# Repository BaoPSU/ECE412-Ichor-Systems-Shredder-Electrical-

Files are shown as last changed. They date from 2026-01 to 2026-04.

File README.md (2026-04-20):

# Universal Plastic Shredder V2.0 — Electrical System

**ECE 412 Senior Project Development I/II · Portland State University · Winter–Spring 2026**

Industry Sponsor: **MME / Ichor Systems** (Bridget Lannigan)
Faculty Advisors: Prof. Andrew Greenberg, Dr. Jonathan Bird (EE), Robert Paxton (ME)

**Team "I'm so Shredded inc.":**

| Name | Email |
|---|---|
| Bao Nguyen | baon@pdx.edu |
| Fearghus Tyler | fearghus@pdx.edu |
| Yaqoub Rabiah | yrabiah@pdx.edu |
| Fox Kang | foxkang@pdx.edu |

---

## Project Overview

Ichor Systems generates significant plastic waste (PVC, polypropylene, LDPE) during semiconductor equipment manufacturing. Existing commercial shredders are either too expensive or underpowered for their thick-material needs (0.25–0.5" rigid sheets). This project designs and builds the **electrical control and power system** for a new industrial-grade plastic shredder — Universal Plastic Shredder V2.0.

The mechanical structure and cutting blades are handled by a separate ME team. The EE team is responsible for:

- VFD-based motor control (3–5 HP, target 70–90 RPM output shaft speed)
- HMI operator interface (ESP32 with display, RS485/MODBUS to VFD)
- Safety systems: two-hand start, emergency stop, lid interlock, overload/overcurrent protection
- PLC ladder logic for control sequencing (DirectLogic 205 / Direct Automation)
- Status indicator lights (Power, Running, Fault)
- Electrical protection: fuses, breakers, motor contactor, thermal shutdown

Design follows **NFPA 70 (NEC)** guidance and **NEMA enclosure** practices. Total project budget is $3,000 (EE portion ~$1,000).

---

## Requirements Summary

**Must:**
- Shred plastic into ~1-inch pieces when integrated with ME system
- Use a controllable VFD; support 3–5 HP motor at 70–90 RPM
- Follow NFPA-70 (NEC) electrical design guidance
- Include emergency stop, overcurrent/overload protection, and at least one safety interlock
- Include an HMI for operator control and status display
- Stay within $3,000 total project budget

**Should:**
- Include clear status and fault indicator lights
- Follow NEMA enclosure guidelines
- Have clearly labeled controls

**May (if time/budget allow):**
- Wireless monitoring (read-only)
- Data logging
- Additional safety sensing (capacitive touch, thermal)

---

## Repository Structure

```
docs/           Project proposal, team contract, HMI options matrix
BOM/            Bill of materials and component selection spreadsheets
CAD/            Mechanical CAD zip archive and Inventor part files (Part1–Part10)
electrical/     Circuit logic diagrams and deadman circuit documentation
PLC/            Shredder ladder logic program
HMI/            HMI project file (MagicPanel .mgp)
```

---

## System Architecture

**Hardware subsystems:**
- AC power input → disconnect → fuses/breakers
- VFD (motor speed and direction control via MODBUS/RS485)
- 3–5 HP motor + gearbox (ME interface)
- ESP32 HMI display (operator interface)
- Safety circuit: two-hand start buttons, E-stop, lid interlock, motor contactor

**PLC (DirectLogic 205 rack — Direct Automation):**
- Ladder logic controls motor run/stop sequencing and safety interlocks
- Program file: `PLC/Shredder_Ladder_logic_v1.dmd`

**Software (Arduino/C++ on ESP32):**
- HMI: displays Ready / Running / Fault state, motor speed, fault messages
- Safety input handling: continuously monitors E-stop, interlocks, two-hand start
- Control logic: manages system states (Idle → Ready → Running → Fault)
- VFD interface: sends run/stop/speed commands, reads fault signals via MODBUS

**Operator workflow:**
1. Power on → safety check
2. Press two-hand start buttons simultaneously to run motor
3. Hand-feed plastic sheets into shredder
4. Normal stop via Stop button, or E-stop if needed
5. Collect shredded output (~1-inch pieces)

---

## Prior Work

A 2023–2024 PSU capstone team built a working 2 HP plastic shredder for the EPL that shredded household plastics with basic VFD, two-hand start, and E-stop. This project scales to industrial-grade plastics and adds motor current monitoring, automatic jam-clearing (auto forward/reverse), thermal shutdown, improved safety interlocks, a proper contactor, and a full HMI.

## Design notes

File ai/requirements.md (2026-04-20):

# Requirements

## Must (M)
| ID | Requirement |
|---|---|
| M1 | Electrical system must safely support shredding plastic into ~1" pieces when integrated with ME system |
| M2 | Controllable VFD must be used |
| M3 | Electrical design must follow NFPA-70 (NEC) guidance |
| M4 | Emergency stop must safely shut down the system |
| M5 | Overcurrent and overload protection must be included |
| M6 | At least one safety interlock must be used |
| M7 | Motor speed must operate around 70–90 RPM |
| M8 | VFD must support a 3–5 HP motor |
| M9 | System must include an HMI for operator control and status display |
| M10 | Total project cost (EE + ME) must remain under $3,000 |

## Should (S)
| ID | Requirement |
|---|---|
| S1 | System should include clear status and fault indicators |
| S2 | Electrical enclosure should follow NEMA-guided practices |
| S3 | Controls should be clearly labeled and easy to understand |

## May (O)
| ID | Requirement |
|---|---|
| O1 | EE electrical cost may target ~$1,000 (subject to change) |
| O2 | Wireless monitoring may be explored (read-only) |
| O3 | Data logging may be implemented |
| O4 | Additional safety sensing (capacitive touch, thermal) may be explored |

## Performance Specs
| Parameter | Value |
|---|---|
| Target shred size | ~1 inch |
| Motor shaft speed | 70–90 RPM (adjustable via VFD) |
| Plastic materials | High-density PVC, PP, LDPE |
| Plastic thickness | 0.25–0.5 inch |
| Plastic width | 4–12 inch |
| Power input | 120 VAC or 208–240 VAC facility supply |
| Total budget | $3,000 (EE + ME) |

## Pass/Fail Test Criteria
- Shreds plastic into ~1" pieces
- VFD controls motor speed with safe start/stop
- E-stop immediately shuts down the system
- Safety interlocks prevent operation when access points are open
- Overcurrent/overload protection triggers under unsafe electrical conditions
- System operates at ~80–90 RPM without electrical faults or exposed wiring

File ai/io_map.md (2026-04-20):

# PLC I/O Map — DirectLOGIC 205 D2-09B-1

## Rack Slot Layout
| Slot | Module | Type | Points |
|---|---|---|---|
| 1 | H2-DM1E | CPU / Ethernet | — |
| 2 | D2-08ND3 | 8-ch DI (24VDC) | X0–X7 |
| 3 | F2-06AD-1 | 6-ch AI (4–20mA / 0–10V) | — |
| 4 | F2-04RTD | 4-ch RTD input | — |
| 5 | D2-08TD2 | 8-ch DO (12–24VDC sourcing) | Y0–Y7 |
| 6 | F2-02DAS-2 | 2-ch AO (4–20mA / 0–10V) | — |
| 7–9 | D2-Fill | Reserved | — |

## Discrete Outputs (D2-08TD2, Slot 5)
| Address | Load | Notes |
|---|---|---|
| Y0 | Mitsubishi SD-N35 Contactor coil A1 | +24VDC via DF103V 1/2A fuse |

## Analog Output (F2-02DAS-2, Slot 6)
| Channel | Destination | Signal |
|---|---|---|
| CH1 | VFD HY02D211B-T terminal AL | 0–10V speed command via ZipLink ZL-RTB20 |

## Output Module — AC Relay (D2-08TA, separate)
| Address | Load | Notes |
|---|---|---|
| OUT0 | TX Contactor (GH15-BN) coil A1 | Via ZipLink, 120VAC common fused 1A slow blow |
| OUT1 | BUS Contactor (GH15-BN) coil A1 | Via ZipLink |
| OUT2 | F1 Contactor (GH15-BN) coil A1 | Via ZipLink |
| OUT3 | Thermal Overload RTD32-180 NC (95→96) | Feeds F2 contactor coil |

## Power Distribution Summary
| Source | Destination | Protection |
|---|---|---|
| Wall AC Line | EURO S10H-5H fuse block | 25A (PSU branch), 1A (PLC branch) |
| NDR-480-24 +V | Pushbutton commons (Fwd, Rev, DM1, DM2) | 1.5A fast blow via EURO S4LH |
| NDR-480-24 –V | Contactor A2, D2-08TD2 COM, D2-08ND3 COM, D2-04RTD COM | Direct return |
| Wall AC (via power switch) | PLC L terminal | 1A fast blow |
| Wall AC (via power switch) | PSU L terminal | 25A slow blow |

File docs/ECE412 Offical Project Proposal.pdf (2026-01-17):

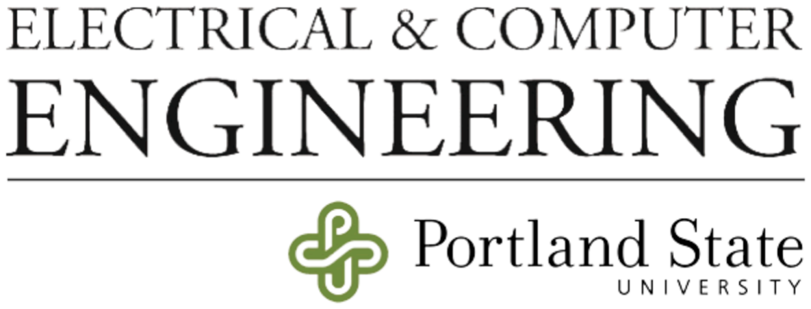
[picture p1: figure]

# Capstone Project Proposal:

# Universal Plastic Shredder V2.0

—————————————————————————————————————— ECE 412 - Senior Project Development I Winter 2026

——————————————————————————————————————— Prof. Andrew Greenberg
Industry Sponsor: MME / Ichor Systems
Faculty Advisor(s): Dr. Jonathan Bird (EE), Robert Paxton (ME)
Authors: Bao Nguyen, Fearghus Tyler, Yaqoub Rabiah, Fox Kang Team Name: I’m so Shredded inc.
Contact: yrabiah@pdx.edu

## Executive Summary

This project is sponsored by MME / Ichor Systems, a company that develops equipment for the semiconductor industry. The main users of this project are workers who handle plastic waste at the company.

The problem is that the company produces a large amount of plastic waste and does not have a cost-effective way to shred and reuse it. Buying large industrial shredders is very costly, and smaller shredders are not strong or safe enough for the types of plastic being handled. The plastic waste includes materials such as PVC, polypropylene (PP), and LDPE, often in the form of thick or rigid parts rather than thin packaging.

This capstone project focuses only on the electrical control and power system for a plastic shredder designed to handle these materials. The mechanical structure, cutting blades, and physical frame are designed by a separate Mechanical Engineering team and are not part of this proposal.

The Electrical Engineering team will design and build the systems that power and control the shredder. This includes motor control, VFD selection, electrical protection, safety interlocks, emergency stop circuits, and operator controls. These systems must be sized and rated based on the expected plastic types and thicknesses (approximately 0.25–0.5 inches thick) so the motor, VFD, and electrical components can be properly selected and tested.

This project will have an impact on the company because it helps reduce waste and allows plastic to be reused instead of being thrown away, which saves money and benefits the environment.

The capstone will be completed over two academic terms at Portland State University, beginning in Winter 2026 and concluding in Spring 2026. During this time, the Electrical Engineering team will design, build, and test the electrical control and safety systems while coordinating with the Mechanical Engineering team for system integration.

By the end of Spring 2026, we will deliver a functional electrical control system integrated with the shredder, along with design documentation and testing results, to the industry sponsor.

## 1. Background and Research

### 1.1 Sponsor Overview

- Ichor Systems is a company that designs and manufactures equipment used in semiconductor production. They focus on systems that safely deliver gas and chemicals needed to make computer chips. These systems control how much gas or liquid is used during the process like etching, cleaning, and coating.
- Ichor also makes metal and plastic ports for the machine. There machines weld, machine, and treat surfaces. And so that is why they produce so much plastic waste when developing these products.
- Ichor Systems headquarters are located in Fremont, California and have facilities across the United States and in other countries. They support over 2,000 employees and major semiconductor manufacturers around the world.

### 1.2 Technology Domain and Context

- Technical Domain:
- This project focuses on electrical control and safety systems used to operate industrial recycling equipment. The scope includes motor control, electrical protection, safety circuits, and operator interfaces. Mechanical structure and cutting mechanisms are handled by a separate Mechanical Engineering team.
- Why These Systems Exist:
- Plastic shredders are used to reduce plastic waste into smaller pieces so it can be recycled or reused. Electrical control systems are required to safely power and control the motors used in shredding equipment and to protect both the operator and the machine.
- How similar Systems Work:
- Most industrial shredders use electric motors controlled by a Variable Frequency Drive (VFD). Safety systems such as emergency stops, interlocks, and overload protection are used to shut the system down if unsafe conditions occur.
- Project Context:
- This shredder will be used as part of Ichor Systems’ waste-handling process to support recycling and reduce plastic waste. This proposal covers only the electrical system required to safely operate the shredder.

### 1.3 Existing System or Prior Work

- What already exists
- In 2024 a previous Portland State University (PSU) capstone team built a working plastic shredder for the Electronic Prototyping Lab (EPL). This shredder shreds common plastics like detergent bottles and left over 3d prints to smaller pieces. It’s powered by a 2HP electric motor, a gear box torque multiplier, and a Variable Frequency Drive (VFD) to control motor speed. This machine also includes basic safety features such as emergency stop and two-hand operation so the machines cannot run unless both buttons are pressed.
- What we are changing and improving
- Electrical safety and control upgrades
- Motor current monitoring for overload detection
- Automatic forward/reverse to clear jams
■ via current overload detection
- Thermal shutdown for overheating protection
- Lid safety interlock
- Status indicator lights
■ Power on status
■ Running
■ Fault
■ Separated from the VFD
- Improve motor start up and shutdown behavior using VFD settings
- Introduce a speed control knob
- Collect data and tune the operating speed
■ Upgrade for fix speed operation
- Add a motor contactor between VFD and motor for extra protection
- Modify the VFD soft start and stop for safe reverse operation
■ Less stress on the motor
- Optional exploration of additional safety sensing (capacitive touch or thermal sensing) to detect human presence near the feed area and trigger a safe shutdown
- Block diagram or figures of the current system

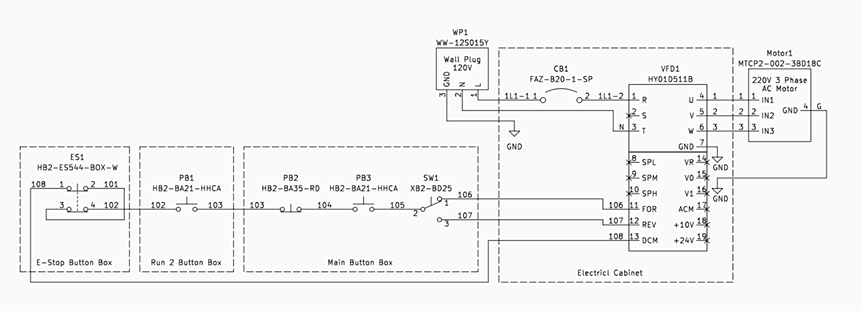
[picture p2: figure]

Electrical Schematic Drawn by: Jasmine Koski (2024)

- The current system takes wall power and sends it to a motor through a VFD. The motor turns a gearbox, which drives the shredder blades. Plastic is fed into the top, shredded inside the cutting chamber, and exits as small pieces. The operator controls the machine using buttons and safety switches.

### 1.5 Research Summary

Commercial Off-the-Shelf Products

### 1. SSI Shredding Systems

a. Model: SSI Dual-Shear® M50
b. What it does: Industrial plastic shredder designed for high-capacity shredding of rigid plastics, containers, and packaging. Uses dual-shaft shear cutters.
c. Suitability:Very effective but expensive and large. It is designed for full-scale recycling facilities, which may be more capacity than needed for an in-house prototype. So expensive that they won't inquire about you unless you are working for the big companies.

### 2. Vecoplab Vaz Series

a. Model: Vecoplan VAZ 1300
b. What it does: Industrial shredder for plastic waste and other materials. Heavy-duty construction with selectable rotor designs.
c. Suitability: Suitable for heavy industrial use, but also $145,700 and over-powered for our use. Offers good examples of safety features and structural design.

### 3. UNTHA Plastic Shredders

a. Model: UNTHA RS40-4
b. What it does: Medium to heavy industrial plastic shredder with four-shaft cutting. Designed for tough plastics and mixed waste streams.
c. Suitability: Professional machine with strong construction. A good industrial standard shredder, but buying one is likely outside the sponsor’s budget considering they don't even list the price.

Open Source Projects

- Project name and license
- Plastic Shredder 2.0
- What it provides
- Open-source designs and documentation for plastic shredders, mainly the electrical control side of things
- What parts are useful
- Example VFD control wiring
- PLC ladder logic structure
- Safety interlock and emergency stop ideas
- Sensor input handling
- General control panel layout ideas

- Limitations or risks
- Most open-source control projects are not designed for industrial environments and do not meet important safety and electrical standards such as NFPA 70 (National Electrical Code), OSHA safety requirements, UL certification, and NEMA enclosure standards. They often do not include proper grounding, fault protection, emergency stop design, or industrial-grade wiring practices. Because of this, these designs cannot be used directly. They are only useful for learning concepts, while the final system must be redesigned to meet real industrial safety and electrical standards.

Patents, Papers, and Articles

- Citation
- Plastic Recycling Shredder Capstone Report, Portland State University (2023–2024)
- Key ideas or results
- The past team successfully designed and built a functional plastic shredder prototype that could shred household plastic into reusable pieces.
- They tested different cutting tooth geometries and showed how tooth shape affects shredding torque and efficiency.
- The machine included a working VFD, forward/reverse control, two-hand safety start, and emergency stop.
- Relevance to our design
- Their work gives us a proven baseline instead of starting from zero.
- The previous report specifically states the system still needs more safety systems and electrical upgrades before it is fully operational, including better protection hardware, braking, interlocks, and improved control design.
- Our project focuses on scaling to a larger industrial system, so we will redesign the electrical system to meet standards such as NFPA 70, NEMA enclosure requirements, UL-style safety thinking, PLC control, industrial-grade wiring, and improved safety interlocks.

## 2. Product Design Specification(Contract)

### 2.1 Product Overview

- What the product or service does
- The Universal Plastic Shredder V2.0 will be a larger, safer, and more powerful plastic shredding system designed to process tougher industrial plastics such as high-density PVC. It will shred plastic sheets into roughly 1-inch pieces using a geared motor system controlled by a VFD and industrial electrical controls.
- The system will include proper fuses, relays, breakers, safety interlocks, and an emergency stop.
- Who uses it
- The shredder will be used by Ichor Systems technicians and operators who handle plastic waste from manufacturing. It may also be used by PSU faculty and students for demonstration and educational purposes.
- How it is used
- Operators will hand-feed plastic sheets into the shredder. Motor speed (target 70–90 RPM) will be controlled using a VFD-based interface. The electrical system will follow industrial wiring practices and provide clear operator controls and safety protections.
- Why the sponsor wants it
- Ichor produces thick plastic waste that the previous student shredder could not safely handle. They want an industrial-style system that is reliable, safe, and compliant with electrical standards, while staying within the $3000 total project budget. Approximately $1000 is allocated to the Electrical Engineering team, subject to change depending on project needs, funding availability, and component sourcing, and not all allocated funds may be used.

### 2.2 Concept of Operations (ConOps)

- Typical user workflow
- Operator powers on the system
- Performs a safety check
- Starts the motor using the control panel
- Feeds plastic into the shredder
- Stops the system normally or uses the emergency stop if needed
- Collects shredded plastic after shutdown
- Inputs, outputs, and interactions
- Inputs: Plastic material, operator control button presses, VFD control signals, safety sensor signals, and power input.
- Outputs: Shredded plastic pieces (target ~1 inch), system status lights, fault indicators, motor speed control, and safety shutdown responses.

- User Interaction: The operator mainly interacts with the control panel, emergency stop, and feed system. The system provides feedback using indicator lights and controls.
- Possible Future Enhancements (Not Guaranteed):
■ If time and budget allow, the team may explore additional features such as a wireless control interface, touchscreen display, data logging, alternative or non-traditional safety sensors, or improved automation. These features are not required for the core system and will only be considered after a safe, fully working shredder system is complete.
- Lifecycle and deployment context
- The system will be designed and tested at PSU and intended for use in a lab or industrial environment. The goal is a durable and serviceable electrical system that can be safely used beyond the capstone project.

### 2.3 Stakeholders

| Stakeholder | Role | Impact on design
Sponsor: | MME / Ichor Systems | Provides project goals, budget, expectations, and final approval. Supplies requirements and feedback. | Drives performance expectations, safety standards, and budget limits. Requires an industrial-style, safe, and reliable shredder design.
End Users: | Technicians/Operator s at Ichor or PSU EPL | Will use the shredder to process plastic waste. Responsible for daily operation, handling materials, and basic maintenance. | Design must prioritize safety, ease of use, clear controls, proper emergency stops, and durable construction suitable for real operation.
Project Team: | Mechanical + Electrical Students | Designs, builds, and tests the system. The mechanical team handles structure and shredding mechanics. The electrical team handles controls, safety, and power systems. | Decisions on components, control systems, safety features, and wiring standards affect cost, complexity, timeline, and overall functionality.

### 2.4 Requirements

Must Requirements

- M1: The electrical system must safely support shredding plastic into ~1-inch pieces when integrated with the mechanical system
- M2: A controllable VFD must be used
- M3: Electrical design must follow NFPA-70 (NEC) guidance
- M4: An emergency stop must safely shut down the system
- M5: Overcurrent and overload protection must be included
- M6: At least one safety interlock must be used
- M7: Motor speed must operate around 70–90 RPM
- M8: The VFD must support a 3–5 HP motor
- M9: The system must include an HMI for operator control and status display
- M10: The total project cost (Electrical + Mechanical) must remain under $3000

Should Requirements

- S1: The system should include clear status and fault indicators
- S2: The electrical enclosure should follow NEMA-guided practices
- S3: Controls should be clearly labeled and easy to understand

May Requirements

- O1: The electrical system cost may target approximately $1000, subject to change based on project needs and funding
- O2: Wireless monitoring may be explored
- O3: Data logging may be implemented
- O4: Additional safety sensing may be explored

### 2.5 Specifications (Optional)

- Quantitative performance targets
- Target shred size: ~1 inch pieces
- Target motor speed: 70–90 RPM (adjustable via VFD)
- Plastic material: High-density PVC, polypropylene (PP), and LDPE, 0.25–0.5 inch thick, 4–12 inch width
- Expected duty cycle: abuse it within reason
- Power requirement: Standard facility AC power (120 VAC or higher industrial supply, such as 208–240 VAC, depending on availability)
- Budget limit: $3000 total project budget (EE + ME), electrical portion subject to change
- Sponsor-imposed technical constraints
- Must safely handle tougher plastics than the previous capstone design

- Must follow industrial-style electrical safety (NFPA-70, NEMA enclosure guidance)
- Must include emergency stop and overload protection
- Must be hand-fed in this version (automation optional for future)
- Must be scalable and designed with potential future improvements in mind

### 2.6 Initial Product Design

Hardware Architecture

- Major subsystems
- Power input, disconnect, and electrical protection
- Control and safety systems
■ 2-hand start, E-stop, interlock, other sensors ■ VFD motor controller
■ HMI operator display interface
■ Motor and mechanical drive interface
- L0 Block diagrams

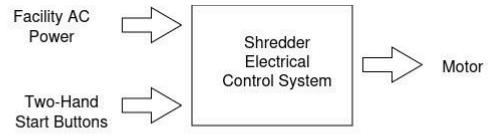
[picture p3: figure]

- L1 Block diagram

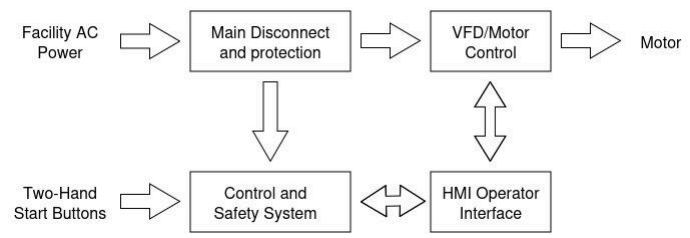
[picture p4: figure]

Software Architecture

- Languages and Environments
- Programming Language: C/C++ (Arduino-style)
- Development Environment: Arduino IDE

- Target Hardware: ESP32 with integrated display (HMI), RS485 to connect to VFD MODBUS safely.
- The Arduino IDE uses a simplified form of C/C++. The code is written in Arduino “sketches,” which are compiled as C/C++ programs.
- Major Modules and Responsibilities
HMI / User Interface
- Displays system status, faults, and speed
- Reads operator inputs (Start, Stop, Reset, Speed control)

Safety Input Handling
- Reads safety signals (emergency stop, two-hand start buttons, interlocks)
- Prevents operation if any safety condition is not met

Control Logic
- Manages system states (Idle, Ready, Running, Fault)
- Controls when the motor is allowed to run

VFD Interface
- Sends run/stop and speed commands to the VFD
- Reads fault or status signals from the VFD if available

Fault Handling
- Detects and displays faults
- Forces safe shutdown behavior

Optional Features
- Basic data logging
- USB serial output for debugging

Data Flow

- Key data paths
- Operator Inputs to ESP32 Control Logic
■ Start, stop, reset, speed settings, and two-hand start buttons are read by the ESP32 through digital inputs or the HMI interface.
- Safety Inputs to Control and Safety Logic
■ Emergency stop, lid/door interlocks, and optional safety sensors are continuously monitored. If any safety condition is violated, the control logic blocks operation or triggers a shutdown.
- ESP32 to VFD
■ The ESP32 sends run/stop commands, direction commands, and speed setpoints to the VFD. The protocol between VFD and ESP32 is unknown, but most commonly used is MODBUS protocol.
- VFD to ESP32
■ The VFD provides status and fault signals back to the ESP32 so the system can display faults and respond safely. Most VFDs from Automation Direct have this capability.

- ESP32 to HMI Display
■ System state, speed, and fault messages are sent to the HMI for operator feedback.
- Storage and communication
- The ESP32 may save simple information such as fault messages or total run time in its built-in memory if needed.
- Communication Interfaces:
■ Digital inputs and outputs for buttons, safety interlocks, and control signals
■ USB connection for programming and debugging
■ Optional Wi-Fi or Bluetooth for monitoring, if used
- No Network Required:
■ The system can operate safely without being connected to the internet or any external network.

User Interface and Experience

- How users interact with the system

The user interacts with the shredder through a simple HMI screen and physical controls. The HMI displays system status such as Ready, Running, or Fault, along with motor speed and basic fault messages.

To start the machine, the operator must press two physical start buttons at the same time. This two-hand control helps keep the operator’s hands away from the feed area during startup. A separate Stop button and Emergency Stop are available to safely shut down the system at any time.

The HMI allows the operator to:
- Start and stop the system
- Adjust motor speed
- View system status and fault messages
- Reset the system after a fault, when safe
- User stories
- As an operator, I want to clearly see whether the system is ready, running, or in a fault state so I know when it is safe to use.
- As an operator, I want the machine to require a two-hand start so my hands are not near moving parts when the shredder begins running.
- As an operator, I want to stop the machine quickly using a stop button or emergency stop if something goes wrong.
- As an operator, I want to see clear fault messages so I know why the system stopped and when it is safe to reset.
- As a technician, I want basic status and fault information on the HMI so troubleshooting is easier.

- As an engineer,I want a maintenance or test page on the HMI that shows the status of safety inputs (such as emergency stop, interlocks, or optional capacitive or thermal sensors) so I can verify that safety systems are working correctly during testing.

Other Considerations

- Security
- The system is designed to operate locally and does not require an internet connection. This reduces security risks related to remote access. Any optional wireless features, if used, will be limited to monitoring and will not allow direct control of the machine. Access to maintenance or test features on the HMI can be restricted to prevent unintended use.
- Safety
- Safety is a primary focus of this project. The electrical system includes an emergency stop, safety interlocks, two-hand start operation, and overload protection to reduce the risk of injury or equipment damage. The control logic is designed so that the system enters a safe state if a fault or unsafe condition is detected. Optional safety sensors, such as capacitive or thermal sensing, may be explored as additional layers of protection but will not replace required safety systems.
- Regulatory compliance
- The electrical system will be designed using industrial-style practices guided by NFPA 70 (National Electrical Code) and general NEMA enclosure guidelines. While full certification (such as UL listing) is outside the scope of this capstone project, safety concepts and wiring practices will follow recognized standards to support safe operation in a lab or industrial environment.

### 2.7 Verification Plan

- How requirements will be tested
- We will test the shredder by running it under real operating conditions. This includes powering the system, controlling it through the VFD and control panel, and shredding real plastic samples that match the sponsor’s material (high-density PVC, 0.25–0.5 in thick). Safety systems such as the emergency stop, interlocks, and overload protection will be tested individually to confirm they work correctly. Torque testing and motor behavior will be verified during initial mechanical testing to ensure the selected motor and gearbox are appropriate.
- Pass/fail criteria
- The shredder must successfully shred plastic into approximately 1-inch pieces.
- The VFD must control motor speed and allow safe start/stop operation.
- The emergency stop must immediately and safely shut down the system.
- Safety interlocks must prevent the system from running when access points are open.

- Overcurrent / overload protection must trigger when unsafe electrical conditions occur.
- System must operate at the target speed (~80–90 RPM)
- The system must operate safely without electrical faults, dangerous exposed wiring, or unsafe behavior.

If any of these fail, the system will be revised and retested.

- Tools and test setups
- Torque testing tools (torque wrench or torque reader as discussed)- could be changed anytime
- VFD configuration and monitoring tools
- Multimeter and electrical testing tools
- Indicator lights / fault monitoring
- Test plastic material supplied by sponsor
- Lab safety supervision during testing

### 2.8 Risks

- Technical risks
- The selected motor or gearbox may not provide enough torque to shred thick PVC material.
- The electrical system may require more protection or safety components than expected.
- Integration between mechanical and electrical systems may be more complex than planned.
- Safety systems (interlocks, E-stop, overload protection) may need redesign to fully meet standards.
- Schedule risks
- Torque testing and motor selection may take longer than expected.
- Mechanical CAD work may delay electrical enclosure planning.
- delivery for motors, VFDs, or electrical components may slow progress.
- Coordination between Mechanical and Electrical teams may impact timing.
- Access to the power lab is unknown
- Resource risks
- Budget limits may restrict component choices.
■ Can also affect the amount of back up equipment
- Availability of used parts or lab equipment may change.
- Limited access to lab space, tools, or testing resources may slow work.
- Mitigation strategies and backup plans
- Perform torque testing early to guide motor and gearbox selection.
- Keep close communication between EE and ME teams to coordinate interfaces.
- Prioritize MUST functionality and safety before optional features.
- Source components early, look for surplus or used equipment to stay inside budget.

- Build in schedule buffer time to handle delays.
- If torque capacity is too low, adjust gearbox ratio or scale mechanical design.

### 2.9 Deliverables

- Project proposal
- Formal written proposal defining scope, objectives, and requirements.(What we are doing here)
- Weekly progress reports
- Short updates documenting progress, challenges, and next steps, scrum.
- Final report
- A full engineering document covering design decisions, analysis, testing, and results.
- Capstone poster
- Would be nice, not necessary
- Brief overview of the main design log documents covering design decisions.
- Working prototype
- Functional electrical control and safety system integrated with the mechanical shredder. Ideally designed in schedule in reference of the ME team.
- Design files and documentation
- Electrical schematics, wiring diagrams, PLC logic (if used), VFD configuration, parts list, safety analysis, and any required NFPA/NEMA compliance documentation to support future use.
- Operators manual
- Debug manual

Delivery Method:

- Github
- Google Drive

## 3. Project Management Plan

### 3.1 Timeline and Milestones

- Research complete by week 3-5
- Initial design finished by week 6-8
- First prototype finished by week 10+
- Integrated prototype 10+
- Final validation 10+

### 3.2 Budget and Resources

The budget is $3,000 for both the ME and EE group.

Item | Cost | Source | When Needed
Motor 3-5 HP? | ~$100-$400? | Second hand? Ask around? Ebay | 3-4th week of the term
VFD? | ~$100-$300? | Reputable online vendor. Automation Direct. Ebay | 3-4th week of the term
Wire/Contacts/Other? | ~$100-$200? | EPL, Ebay, Amazon | 3-4th week of the term

### 3.3 Intellectual Property

- IP ownership
- All work produced during this capstone project will be released as open-source. The project team and Portland State University retain authorship of the work, and the sponsor is permitted to use the results.
- Licensing terms
- Project materials such as source code, schematics, and documentation will be shared under an open-source license to allow reuse, modification, and educational use.
- Sponsor agreements
- The project will follow Portland State University policies and agreements with MME / Ichor Systems. No confidential or proprietary information will be included in the open-source materials.

### 3.4 Team

Team members: Bao Nguyen, Fearghus Tyler, Yaqoub Rabiah, Fox Kang

- Bao Nguyen will focus on documentation and assist with programming and setting up the HMI, including the GUI layout, icons, and status indicators, and assist with connecting the HMI/ESP32 to the VFD.
- Fearghus Tyler will serve as the team lead and primary point of contact with the sponsor, and will focus on research, the bill of materials (BOM), and overall electrical safety planning.
- Yaqoub Rabiah will focus on start/stop controls, emergency stop integration, and VFD selection, wiring, and programming, and may also assist with ESP32 HMI programming as needed.
- Fox Kang will focus on system integration, safety circuit layout, and evaluation of advanced safety sensing such as capacitive touch or thermal sensors.

Roles and responsibilities are subject to change over the course of the project based on project needs and team availability.

### 3.5 Development Tools and Process

- We have a good deal of tested devices to draw from, the shredding industry is fairly old and established.
- For collaboration, a google drive is sufficient.
- Microsoft Planner or Trello used for scheduling.
- Github

### Sponsor Approval

By signing below, the undersigned acknowledges review of this proposal and agrees with the project scope and objectives as described.

Industry Sponsor Representative:

Name:_Bridget Lannigan__________

Organization:__Ichor Systems_______

Signature:___________________________

Date:___January 16th, 2026_____

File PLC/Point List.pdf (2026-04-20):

# Index

### POINT ASSIGNMENT INDEX

| PAGE NO. | NO. OF SHEETS | DESCRIPTION
| 1.0 | 1.0 | Mitsubishi SD-N35
| 2.0 | 2.0 | Mean Well NDR-480-24
| 3.0 | 3.0 | Direct Logic 205 D2-09B-1
| REV | DATE | DESCRIPTION | Created By | Checked by
| 1.0
| 2.0
| 2.0
| 2.0
| 3.0
| 4.0

# Mitsubishi SD-N35

Mitsubishi SD-N35 | | POINT TYPE
| | Hardware Point | | | | | Virtual Point
Point Description | Origin Address | DO | DI | AO | AI | Pwr | | Destination Address | Destination Description | Notes
Contactor (Mitsubishi SD-N35) ? Coi A1 | 0.0 | 0.0 | 0.0 | 0.0 | 1.0 | 0.0 | Y0 | D2-08TD2 Output Module (12?24VDC)A1 ? DF103V (1/2A slow blow fuse) ?
Contactor (Mitsubishi SD-N35) ? Coi A2 | | 0.0 | 0.0 | 0.0 | 0.0 | 1.0 | 0.0 | -V | NDR-480-24 Power Supply | A2 ? direct return to power supply
Contactor (Mitsubishi SD-N35) ? Lin | L1 | 0.0 | 0.0 | 0.0 | 0.0 | 1.0 | 0.0 | L | Phoenix Contact TMC 83C 15A (290761 L1 ? Phoenix Contact fuse breaker ?
Contactor (Mitsubishi SD-N35) ? LoaT1 | | 0.0 | 0.0 | 0.0 | 0.0 | 1.0 | 0.0 | R | HY Series VFD (HY02D211B-T) | T1 ? passes through contactor ? sup
| Total Points | =SUM(C5:C8) | =SUM(D5:D8) =SUM(E5:E8) | | =SUM(F5:F8) | =SUM(G5:G8) =SUM(H5:H8)

# Mean Well NDR-480-24

Mean Well NDR-480-24 | | POINT TYPE
| | Hardware Point | | | | | Virtual Point
Point Description | Origin Address | DO | DI | AO | AI | Pwr | | Destination Address | Destination Description | Notes
DC Power Supply (Mean Well NDR-480- | L | 0.0 | 0.0 | 0.0 | 0.0 | 1.0 | | L | MORSETTITALIA EURO S10H-5H Fuse BloLine from wall -> passes through po
DC Power Supply (Mean Well NDR-480- | N | 0.0 | 0.0 | 0.0 | 0.0 | 1.0 | | N | Neutral Bus | Neutral from supply -> directly con
DC Power Supply (Mean Well NDR-480- | G | 0.0 | 0.0 | 0.0 | 0.0 | 1.0 | | G | Ground Bus | Protective earth -> connected to PS
DC Power Supply (Mean Well NDR-480- | -V | 0.0 | 0.0 | 0.0 | 0.0 | 1.0 | | A2 | Mitsubishi SD-N35 Contactor | -V from power supply -> connected t
DC Power Supply (Mean Well NDR-480- | -V | 0.0 | 0.0 | 0.0 | 0.0 | 1.0 | | COM | D2-08TD2 Output Module | -V from power supply -> connected t
DC Power Supply (Mean Well NDR-480- | -V | 0.0 | 0.0 | 0.0 | 0.0 | 1.0 | | COM | D2-08ND3 Input Module | -V from power supply -> connected t
DC Power Supply (Mean Well NDR-480- | -V | 0.0 | 0.0 | 0.0 | 0.0 | 1.0 | | COM | D2-04RTD Module | -V from power supply -> connected t
DC Power Supply (Mean Well NDR-480- | +V | 0.0 | 0.0 | 0.0 | 0.0 | 1.0 | | IN | MORSETTITALIA EURO S4LH Terminal Bl+24V from power supply -> enters te
| Total Points | 0.0 | 0.0 | 0.0 | 0.0 | 5.0

# Direct Logic 205 D2-09B-1

Direct Logic 205 D2-09B-1 | | POINT TYPE
| | Hardware Point | | | | | Virtual Point
Point Description | Origin Address | DO | DI | AO | AI | Pwr | | Destination Address | Destination Description | Notes
PLC Rack (DirectLOGIC 205) ? Base | Base | 0.0 | 0.0 | 0.0 | 0.0 | 1.0 | ? | D2-09B-1 | Base / Power Unit | Rack base unit providing backplane
PLC Rack (DirectLOGIC 205) ? Line I | L | 0.0 | 0.0 | 0.0 | 0.0 | 1.0 | ? | L | MORSETTITALIA EURO S10H-5H Fuse BloLine from wall -> passes through po
PLC Rack (DirectLOGIC 205) ? Neutra | N | 0.0 | 0.0 | 0.0 | 0.0 | 1.0 | ? | N | Neutral Bus | Neutral from wall -> directly conne
PLC Rack (DirectLOGIC 205) ? Ground | G | 0.0 | 0.0 | 0.0 | 0.0 | 1.0 | ? | G | Ground Bus | Protective earth -> connected to PL
PLC Rack (DirectLOGIC 205) ? Slot 1 | Slot 1 | 0.0 | 0.0 | 0.0 | 0.0 | 0.0 | ? | H2-DM1E | CPU / Ethernet Module | CPU module with built-in Ethernet p
PLC Rack (DirectLOGIC 205) ? Slot 2 | Slot 2 | 0.0 | 8.0 | 0.0 | 0.0 | 0.0 | ? | D2-08ND3 | 8-Point Discrete Input Module | 8-channel 24VDC discrete (digital)
PLC Rack (DirectLOGIC 205) ? Slot 3 | Slot 3 | 0.0 | 0.0 | 0.0 | 6.0 | 0.0 | ? | F2-06AD-1 | 6-Channel Analog Input Module | 6-channel analog input module. Acce
PLC Rack (DirectLOGIC 205) ? Slot 4 | Slot 4 | 0.0 | 0.0 | 0.0 | 4.0 | 0.0 | ? | F2-04RTD | 4-Channel RTD Input Module | 4-channel RTD (Resistance Temperatu
PLC Rack (DirectLOGIC 205) ? Slot 5 | Slot 5 | 8.0 | 0.0 | 0.0 | 0.0 | 0.0 | ? | D2-08TD2 | 8-Point Discrete Output Module | 8-channel 12?24VDC transistor (sour
PLC Rack (DirectLOGIC 205) ? Slot 6 | Slot 6 | 0.0 | 0.0 | 2.0 | 0.0 | 0.0 | ? | F2-02DA-1 | 2-Channel Analog Output Module | 2-channel analog output module. Pro
PLC Rack (DirectLOGIC 205) ? Slot 7 | Slot 7 | ? | ? | ? | ? | ? | ? | D2-Fill | Fill Panel | Blank fill panel. No I/O. Slot rese
PLC Rack (DirectLOGIC 205) ? Slot 8 | Slot 8 | ? | ? | ? | ? | ? | ? | D2-Fill | Fill Panel | Blank fill panel. No I/O. Slot rese
PLC Rack (DirectLOGIC 205) ? Slot 9 | Slot 9 | ? | ? | ? | ? | ? | ? | D2-Fill | Fill Panel | Blank fill panel. No I/O. Slot rese

# DirectLOGIC CPU (H2-DM1E)

DirectLOGIC PLC CPU(H2-DM1E) | | POINT TYPE
| | Hardware Point | | | | | Virtual Point
Point Description | Origin Address | DO | DI | AO | AI | Pwr | | Destination Address | Destination Description | Notes
Power and communication interface | Backplane Connector (Left Edge) | 0.0 | 0.0 | 0.0 | 0.0 | 1.0 | 0.0 | D2-09B-1 Base Slot 1 Connector | Provides power and backplane commun ?
Ground reference | Backplane GND | 0.0 | 0.0 | 0.0 | 0.0 | 1.0 | 0.0 | D2-09B-1 Base Ground Bus | Common ground for logic power | ?
| Total Points | =SUM(C5:C6) | =SUM(D5:D6) | =SUM(E5:E6) | =SUM(F5:F6) | =SUM(G5:G6) =SUM(H5:H6)

# Output Module (D2-08TA)

Output Module (D2-08TA) | | POINT TYPE
| | Hardware Point | | | | | Virtual Point
Point Description | Origin Address | DO | DI | AO | AI | Pwr | | Destination Address | Destination Description | Notes
Output Common (Hot) | C | 1.0 | 0.0 | 0.0 | 0.0 | 1.0 | 0.0 | 120 V Hot Bus | ZipLink Terminal Block (ZL-RTB20-OU120 V hot feed shared by all output
Output 0 | OUT0 | 1.0 | 0.0 | 0.0 | 0.0 | 0.0 | 0.0 | A1 | TX Contactor (GH15-BN) | Drives TX coil via ZipLink
Output 1 | OUT1 | 1.0 | 0.0 | 0.0 | 0.0 | 0.0 | 0.0 | A1 | BUS Contactor (GH15-BN) | Drives BUS coil via ZipLink
Output 2 | OUT2 | 1.0 | 0.0 | 0.0 | 0.0 | 0.0 | 0.0 | A1 | F1 Contactor (GH15-BN) | Drives F1 coil via ZipLink
Output 3 | OUT3 | 1.0 | 0.0 | 0.0 | 0.0 | 0.0 | 0.0 | 95.0 | Thermal Overload Relay (RTD32-180)Feeds NC contact 95 ? 96 ? F2 coil
Module Power Feed | Backplane | 0.0 | 0.0 | 0.0 | 0.0 | 1.0 | 0.0 | Slot 3 Connector | PLC base backplane (120 VAC) | No external wiring
| Total Points | =SUM(C5:C10) | =SUM(D5:D10) | =SUM(E5:E10) | =SUM(F5:F10) | =SUM(G5:G10) =SUM(H5:H10)

# HMI (EA9-T6CL-R)

6? C-More color touch panel HMI (EA | | POINT TYPE
| | Hardware Point | | | | | Virtual Point
Point Description | Origin Address | DO | DI | AO | AI | Pwr | | Destination Address | Destination Description | Notes
HMI Serial Comm Port | COM Port | 0.0 | 0.0 | 0.0 | 0.0 | 0.0 | 1.0 | Serial Port | H2-DM1E | Serial link between PLC CPU and C-M
HMI Power +V | +VDC | 0.0 | 0.0 | 0.0 | 0.0 | 1.0 | 0.0 | +V | Rhino power supply(PSB12-030-P) | HMI DC input powered from PSB12-030
HMI Power 0 V | 0VDC | 0.0 | 0.0 | 0.0 | 0.0 | 1.0 | 0.0 | 0V | Rhino power supply(PSB12-030-P) | 0 VDC return to Rhino power supply;
HMI Ground | Ground | 0.0 | 0.0 | 0.0 | 0.0 | 1.0 | 0.0 | Ground | Ground
| Total Points | =SUM(C5:C8) | =SUM(D5:D8) =SUM(E5:E8) | | =SUM(F5:F8) | =SUM(G5:G8) =SUM(H5:H8)

# Output Module (F2-02DAS-2)

Output Module (F2-02DAS-2) | | POINT TYPE
| | Hardware Point | | | | | Virtual Point
Point Description | Origin Address | DO | DI | AO | AI | Pwr | | Destination Address | Destination Description | Notes
Analog Common (CH1) | CH1-V | 0.0 | 0.0 | 1.0 | 0.0 | 0.0 | 0.0 | CM | VFD (GS1-20P2) through Ziplink ZL-R0V1 and CH1-V are internally shorte
Analog Output CH1 | CH1+V | 0.0 | 0.0 | 1.0 | 0.0 | 0.0 | 0.0 | AL | VFD (GS1-20P2) though Ziplink ZL-RT0?10 V speed command to VFD
Module Logic +24 V | +V1 | 0.0 | 0.0 | 0.0 | 0.0 | 1.0 | 0.0 | VDC +24V | PLC Base (D2-09B-1) through ZipLinkPowers analog output circuitry, als
Module Logic 0 V | 0V1 | 0.0 | 0.0 | 0.0 | 0.0 | 1.0 | 0.0 | VDC ? 0V | PLC Base (D2-09B-1) through ZipLinkCommon return for module logic
Slot Power Feed | Backplane | 0.0 | 0.0 | 0.0 | 0.0 | 1.0 | 0.0 | PLC Base Backplane | Internal slot power | No external wiring
| Total Points | =SUM(C5:C9) | =SUM(D5:D9) | =SUM(E5:E9) | =SUM(F5:F9) | =SUM(G5:G9) =SUM(H5:H9)

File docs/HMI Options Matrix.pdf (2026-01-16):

HMI Display Matrix Options
Criteria | Display 1 | Display 2 | Display 3 | Display 4 | Display 5 | Display 6 | Display 7 | Display 8
Manufacturer | AutomationDirect | AutomationDirect | ELECROW | Waveshare | Waveshare | NEXTION | Siemens | Siemens
Model | EA3-T6CL | EA9-T7CL | CrowPanel ESP32-S3 (7") | ESP32-S3-Touch-LCD-7 | ESP32-S3-Touch-LCD-7B (Type B) | NX8048P070-011C (Intelligent Series) | SIMATIC HMI KTP600 (6AV6647-0AC11-3AX0) | SIMATIC HMI SMART 700 IE (6AV6648-0CC11-3AX0)
Screen Size (inches) | 6 | 7 | 7 | 7 | 7 | 7 | 6 | 7
Resolution | 320 × 240 | 800 × 480 | 800 × 480 | 800 × 480 | 1024 × 600 | 800 × 480 | 640 × 480 | 800 × 480
Touch Type | Resistive | Resistive | Capacitive | 5-point capacitive | 5-point capacitive (optional) | Capacitive | Resistive | Resistive
Display Panel | TFT | TFT | TFT (TN) | IPS (170°) | IPS (170°) | TFT LCD (65K color) | TFT LCD | TFT LCD
Mount Type | Panel mount (NEMA 4/4X front) | Panel mount (NEMA 4/4X front) | Standalone acrylic case | Dev board / enclosure DIY | Dev board / enclosure DIY | Panel-mount style (front mount); some versions include enclosure | Panel mount (industrial front mount) | Panel mount (industrial front mount)
MCU | Proprietary | Proprietary | ESP32-S3 (LX6, up to 240 MHz) | ESP32-S3 (LX7 dual-core, up to 240 MHz) | ESP32-S3 (LX7 dual-core, up to 240 MHz) | NXP-based, 200 MHz (on-display MCU) | Proprietary Siemens HMI CPU | Proprietary Siemens HMI CPU
Memory | Internal flash | Internal flash + SD | 4 MB Flash + 8 MB PSRAM | 16 MB Flash + 8 MB PSRAM | 16 MB Flash + 8 MB PSRAM | 128 MB Flash, 512 KB SRAM | Internal (Siemens-managed) | Internal Siemens-managed flash / RAM
IO / Interfaces | None (HMI only) | None (HMI only) | GPIO, UART, I²C, USB, battery | CAN, RS485, UART, I²C, USB-C, TF, sensor headers | CAN, RS485, UART, I²C, USB-C, TF, sensor headers + 5V out | UART (TTL serial) to ESP32/Arduino; onboard features vary by series (often includes GPIO/RTC on Intelligent) | PROFINET, USB (service) | PROFINET (Ethernet), USB (service/programming)
Connectivity | Serial / USB (Ethernet optional) | Serial / USB / Ethernet | Wi-Fi + Bluetooth | Wi-Fi + Bluetooth 5 | Wi-Fi + Bluetooth 5 | None (wired UART; no Wi-Fi on the display itself) | Industrial Ethernet (PROFINET) | Industrial Ethernet (PROFINET)
Development Environment | C-more Micro | C-more EA9 | Arduino, ESP-IDF, PlatformIO, MicroPython, LVGL | Arduino, ESP-IDF, LVGL | Arduino, ESP-IDF, LVGL | Nextion Editor (drag-and-drop HMI + event code on screen) | Siemens TIA Portal / WinCC | WinCC flexible SMART (free)
Operating Voltage | 24 VDC | 24 VDC | 5 VDC | 5 VDC or Li-ion | 5 VDC or Li-ion | 5 V | 24 VDC | 24 VDC
Extra features | — | SD logging (EA9) | Case + speaker/battery interfaces vary | — | Backlight adjustment + battery voltage monitoring + charge indicators | Audio/video/animation support, RTC support (per Intelligent series listing) | Alarms, trends, PLC tag binding | Alarms, trends, PLC tag binding, recipes
Cost | ≈ $470 | ≈ $700–750 | ≈ $50 | ≈ $37–40 | ≈ $34–39 | ≈$122 | ≈ $500–900(Used) | ≈ $130–220 (used market)
Support Level | Medium | Medium | Medium–Low | Medium–High | Medium–High | High | High | High
Support Rationale | Good vendor support, weak onboarding/docs | Same as EA3. I have experince with this. | Mixed docs, more self-debugging | Strong wiki/examples/pinouts | Same as Display 4, plus it’s the “upgraded” higher-res version. Looks like a good balance | Easiest path for buttons + live telemetry via simple serial commands according to reddit. But closed source | Excellent industrial documentation and support, closed ecosystem. Wicked expesnive | Strong Siemens documentation and long-term industrial support; closed ecosystem
Industry Standard? | Yes | Yes | No | No | No | Yes | Yes | Yes

The problem with using an industry-standard HMI is that it often needs extra external modules to work with sensors, buttons, and the motor controller. These extra parts increase the total cost. In comparison, an ESP32-based HMI from Elecrow already includes built-in inputs and communication features, which reduces the number of extra components needed and helps keep the system cheaper and simpler. For example, using the AutomationDirect EA9, the HMI along with the required PLC, digital I/O, and analog I/O modules can cost $700–$1,200+ used, not including the VFD or motor, which are already allocated for this project. In contrast, an open-source ESP32-based HMI such as an Elecrow or Waveshare display, including any required modules to communicate over Modbus, would cost under $150–$300 total but at the cost of not being industry rated.

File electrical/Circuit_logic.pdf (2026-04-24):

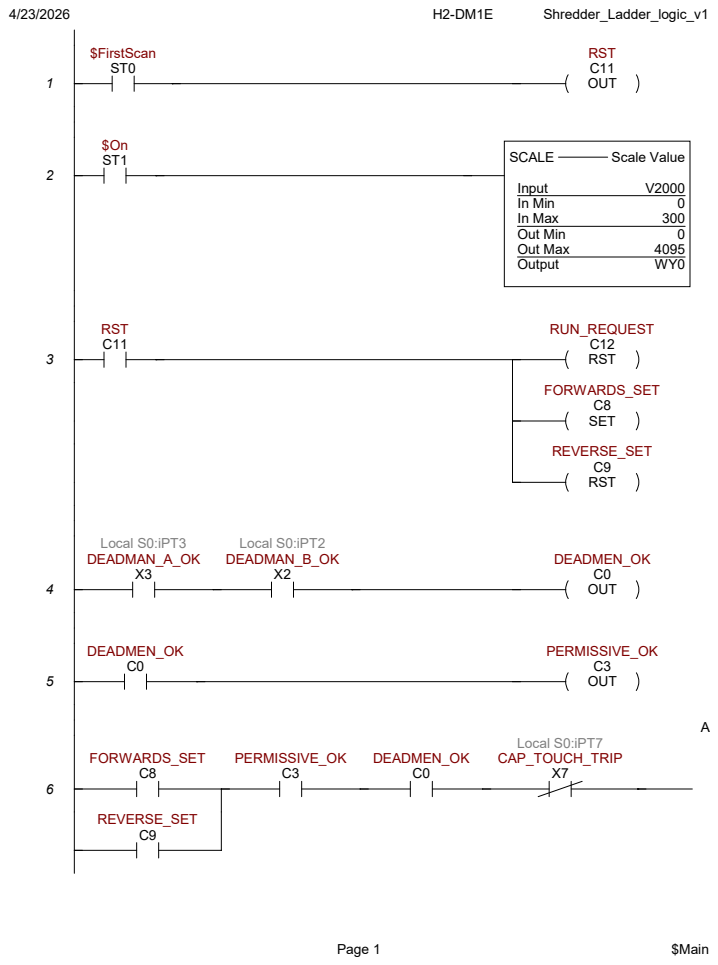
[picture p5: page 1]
Shredder_Ladder_logic_v1; $FirstScan ST0; OUT; RST C11; SCALE; Scale Value; Input; In Min; In Max; Out Min; Out Max; Output; RST; RUN_REQUEST C12; SET; FORWARDS_SET C8; REVERSE_SET C9; Local S0:iPT3 DEADMAN_A_OK X3; Local S0:iPT2 DEADMAN_B_OK X2; DEADMEN_OK C0; PERMISSIVE_OK C3; Local S0:iPT7 CAP_TOUCH_TRIP X7; Page 1; $Main

SET

RUN_REQUEST
C12

A

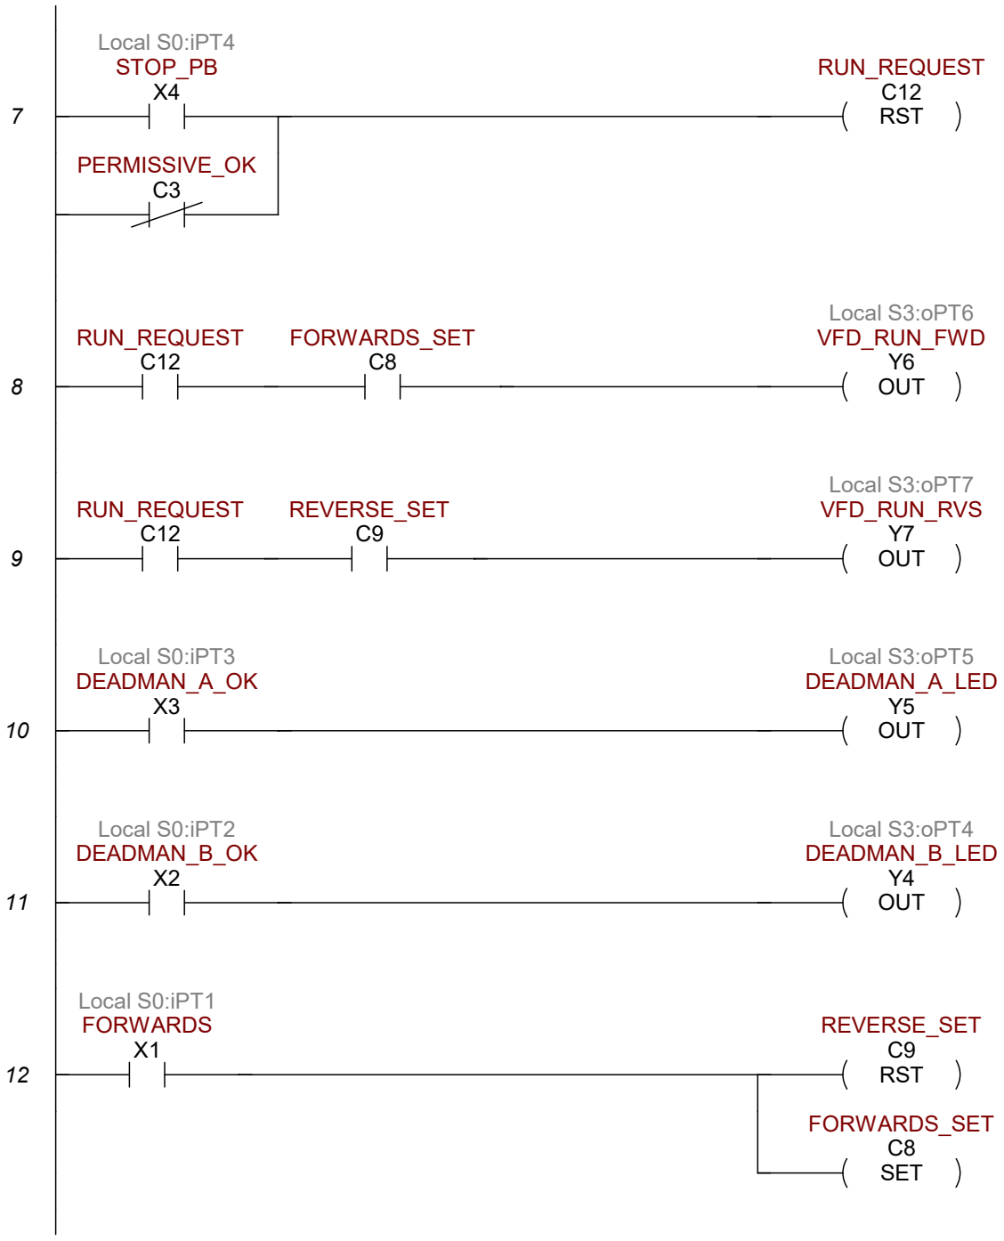
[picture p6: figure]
Local S0:iPT4 STOP_PB X4; RST; RUN_REQUEST C12; PERMISSIVE_OK C3; FORWARDS_SET C8; OUT; Local S3:oPT6 VFD_RUN_FWD Y6; REVERSE_SET C9; Local S3:oPT7 VFD_RUN_RVS Y7; Local S0:iPT3 DEADMAN_A_OK X3; Local S3:oPT5 DEADMAN_A_LED Y5; Local S0:iPT2 DEADMAN_B_OK X2; Local S3:oPT4 DEADMAN_B_LED Y4; Local S0:iPT1 FORWARDS X1; SET

Page 2 | $Main

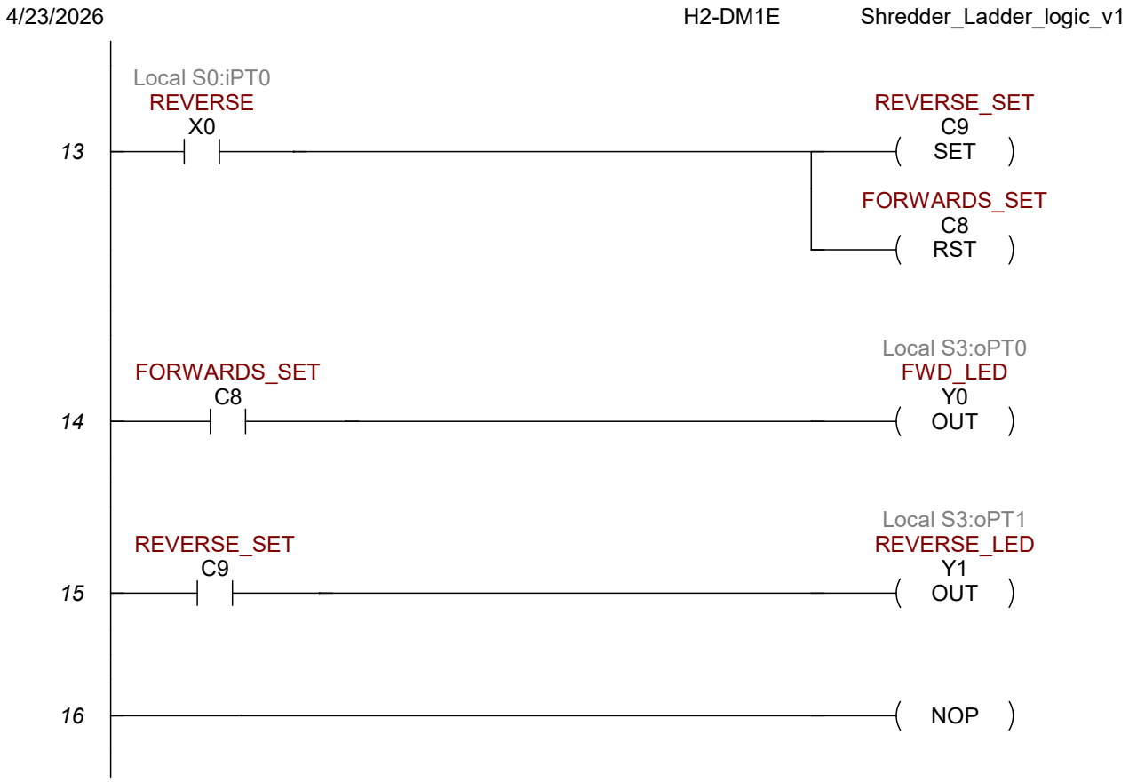
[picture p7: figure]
Local S0:iPT0 REVERSE X0; SET; REVERSE_SET C9; RST; FORWARDS_SET C8; OUT; Local S3:oPT0 FWD_LED Y0; Local S3:oPT1 REVERSE_LED Y1; 16 NOP

Page 3 | $Main

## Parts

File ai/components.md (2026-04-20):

# Hardware Components

## PLC System
| Component | Model | Notes |
|---|---|---|
| PLC Rack | DirectLOGIC 205 D2-09B-1 | 9-slot base unit |
| CPU | H2-DM1E | Built-in Ethernet, executes ladder logic |
| Discrete Input | D2-08ND3 | 8-ch 24VDC digital inputs (Slot 2) |
| Analog Input | F2-06AD-1 | 6-ch 4–20mA / 0–10V (Slot 3) |
| RTD Input | F2-04RTD | 4-ch PT100/PT1000 temp (Slot 4) |
| Discrete Output | D2-08TD2 | 8-ch 12–24VDC transistor sourcing (Slot 5) |
| Analog Output | F2-02DAS-2 | 2-ch 4–20mA / 0–10V (Slot 6) |
| Fill Panels | D2-Fill | Slots 7, 8, 9 (reserved) |

## HMI
| Component | Model | Notes |
|---|---|---|
| Touch Panel | EA9-T6CL-R | 6" C-More color touch panel |
| HMI Power Supply | Rhino PSB12-030-P | DC supply for HMI |
| PLC–HMI Link | Serial (COM port) | Match baud/parity/stop bits on both ends |

## Power
| Component | Model | Notes |
|---|---|---|
| 24VDC Power Supply | Mean Well NDR-480-24 | Powers PLC I/O, contactor coil, pushbutton commons |
| Fuse Block (main) | MORSETTITALIA EURO S10H-5H | 25A for PSU branch, 1A for PLC branch |
| Pushbutton fuse | MORSETTITALIA EURO S4LH | 1.5A fast blow, distributed to pushbutton commons |

## Motor Control
| Component | Model | Notes |
|---|---|---|
| VFD | HY Series HY02D211B-T | Receives 0–10V speed command via analog output CH1 |
| Contactor | Mitsubishi SD-N35 | Coil driven by D2-08TD2 Y0 output (+24VDC) |
| Motor Overload | Phoenix Contact TMC 83C 15A (2907618) | AC line protection before contactor |
| Thermal Overload | RTD32-180 | NC contact feeds F2 coil; driven by OUT3 |

## Safety / Control
| Component | Notes |
|---|---|
| E-stop | Hardwired NC into safety circuit |
| Two-hand start | Forward + Deadman SW1 + Deadman SW2 buttons (24VDC, fused 1.5A) |
| Lid interlock | DI input to PLC |
| Status lights | Power on / Running / Fault (driven by discrete outputs) |

## Wiring Accessories
| Component | Model | Notes |
|---|---|---|
| ZipLink Terminal Block | ZL-RTB20-OUT | Output module field wiring interface |
| ZipLink Terminal Block | ZL-RTB20 | Analog output field wiring interface |
| Contactor fuse | DF103V 1/2A slow blow | Protects D2-08TD2 output to contactor coil A1 |

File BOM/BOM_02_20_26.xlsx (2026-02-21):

Level | Number | Description | Make/Buy | Commodity Code: | Critical Flag | Product Family | Seq / Find Num | Qty | Manufacturer | Manufacturer PN
0 | 1 | Motor | Buy | MOT-AC | YES | ELECTRICAL |  | 1 |  | PE145TC-2-4 | https://www.electricmotorsforless.com/PE145TC-2-4-2-hp-145TC-electric-motor-1800-3-phase-tefc-North-American-_p_215.html
. 1 | 2 | HMI | Buy | HMI-PNL | YES | CONTROLS |  | 1 |  | EA1-T4CL | https://www.ebay.com/itm/306662618920?_skw=EA1-T4CL&itmmeta=01KFFHPKRB7RPJFFXXP1CYXW9A
.. 2 | 3 | Circuit BKR | Buy | CIR-BRK | NO | ELECTRICAL |  | 1 |  | NBE7 | https://www.ebay.com/itm/193359270352?_trksid=p4375194.c102726.m162918
 | 4 | Power switch | Buy | SW-PWR | NO | ELECTRICAL |  | 1 |  | 71008 | https://powertecproducts.com/71008-single-phase-on-off-switch-120-230v/?setCurrencyId=1&sku=71008
 | 5 | VFD | Buy | DRV-VFD | YES | CONTROLS |  | 1 |  | HY02D211B-T | https://www.amazon.com/Huanyang-1-Phase-Variable-Frequency-Output-3hp/dp/B0DMF3GB38?th=1
 | 6 | Red/Green Lights |  | LMP-LED | NO | ELECTRICAL |  | 1 |  |  | Ichor Provided?
 | 7 | E-stop |  | SW-ESTOP | YES | CONTROLS |  | 1 |  |  | Ichor Provided?

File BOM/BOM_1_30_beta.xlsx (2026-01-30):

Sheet: Bill of Materials
PRODUCT NAME | Shreddar | EE TEAM
APPROVED BY |  | Fearghus Tyler
DATE OF APPROVAL |  | Bao
PART COUNT | 16 | Yacoub
TOTAL COST | $785.00 | Fox
PART NUMBER | PART NAME | DESCRIPTION | QUANTITY | UNITS | LINK | UNIT COST | AMOUNT
TBD | Motor |  | 1 |  |  |  | $0.00
‎HY02D211B-T | VFD | Huanyang 3HP VFD | 1 |  | https://www.amazon.com/Huanyang-1-Phase-Variable-Frequency-Output-3hp/dp/B0DMF3GB38 | $200.00 | $200.00
MITSUBISHI SD-N35 | Contactor | Primary contactor rated for over 3HP | 1 |  | https://www.ebay.com/itm/186247548349 | $35.00 | $35.00
TBD | Push Button | Various, Assorted | 2 |  |  | $0.00 | $0.00
TBD | Wire | Various, Assorted. 12AWG, 10AWG as needed | 2 |  |  | $0.00 | $0.00
EA1-T4CL, H2-DM1E, 2-08ND3, F2-04RTD, F2-08AD-1, D2-08TD2, F2-02DA-1, and 3 D2-FILL | PLC RACK + MODULES | PLC Rack with modules attached for date in, data out and system monitoring. | 1 |  | https://www.ebay.com/itm/256889890703 | $340.00 | $340.00
TBD | Din Rail | As needed | 2 |  |  | $0.00 | $0.00
EA1-T4CL | HMI | Automation direct C-more micro graphic TFT touch screen HMI panel | 1 |  | https://www.ebay.com/itm/306662618920?_skw=EA1-T4CL&itmmeta=01KFFHPKRB7RPJFFXXP1CYXW9A | $125.00 | $125.00
NBE7 | Circuit Breaker | Rated for the appropriate inrush current (25Amp) | 1 |  | https://www.ebay.com/itm/193359270352?_trksid=p4375194.c102726.m162918 | $16.00 | $16.00
71008 | Power Switch | Basic On/Off switch | 1 |  | https://powertecproducts.com/71008-single-phase-on-off-switch-120-230v/?setCurrencyId=1&sku=71008 | $15.00 | $15.00
TBD | Fuse | 30Amp | 2 |  |  | $27.00 | $54.00
1866-1441-ND | Power Supply | 120 24VDC Power supply | 1 |  | https://www.digikey.com/en/products/detail/mean-well-usa-inc/EDR-120-24/7702914?gclsrc=aw.ds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 |  | $0.00
 |  |  |  |  |  |  | $0.00
 |  |  |  |  |  |  | $0.00
 |  | TOTAL PARTS | 16 |  |  | TOTAL | $785.00
CREATE YOUR BILL OF MATERIALS TEMPLATE IN SMARTSHEET (https://goo.gl/cTwMSE)

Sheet: BOM of Safety methods Draft
PART NUMBER | PART NAME | DESCRIPTION | QUANTITY | UNITS | LINK | UNIT COST | AMOUNT | Remarks
 | ~~TTP223B~~ | ~~A single-channel capacitive touch detection chip~~ | ~~1~~ |  | ~~https://www.digikey.com/short/hhr5h222~~ | ~~UNKNOWN(No-in stock)~~ | ~~1~~ | ~~Does not meet industrial standards~~
 | CAP1293-1-SN | 3-CHANNEL CAPACITIVE TOUCH SENSO | 1 |  | https://www.digikey.com/short/vnvrdw7z | 0.78 | 1 | chip only,need to transfer RS485 to I2C
 | 1864-1032-ND | SENSOR PROX CAP 3-12MM CYLINDER | 1 |  | https://www.digikey.com/short/3jzp4r9w | 109.25 | 1 | expensive
 | F3S-TGR-N_C | Series Magnetic Non-Contact Safety Switch, 24V dc, Plastic Housing, NO/2NC, 10m Cable | 1 |  | F3S-TGR-NMPC-21-10 | Omron F3S-TGR-N_C Series Magnetic Non-Contact Safety Switch, 24V dc, Plastic Housing, NO/2NC, 10m Cable | RS (https://uk.rs-online.com/web/p/non-contact-safety-switches/7579253?msockid=1cab04cc9edd6dab0e33126c9f676ced) | £143.26 | 1 | expensive, didn't find on amazon or digikey
 | RSS 36-I2-D-R-ST5 | RFID-technology for needs-based protection against tampering | 1 |  | RSS 36-I2-D-R-ST5 - Schmersal (https://products.schmersal.com/en_IO/rss-36-i2-d-r-st5-103025100.html) | ? | 1 | Suspected non-retail
 | F3SG-SR / PG Series | Safety Light Curtain | 1 |  | https://www.ia.omron.com/products/family/3736/ | TBD | 1 | Need to be decided according to the size of open mouth

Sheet: - Disclaimer -
Any articles, templates, or information provided by Smartsheet on the website are for reference only. While we strive to keep the information up to date and correct, we make no representations or warranties of any kind, express or implied, about the completeness, accuracy, reliability, suitability, or availability with respect to the website or the information, articles, templates, or related graphics contained on the website. Any reliance you place on such information is therefore strictly at your own risk.

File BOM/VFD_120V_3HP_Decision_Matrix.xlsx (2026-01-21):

Option | Price Score (50%) | Current Capability (20%) | Build Quality (15%) | Documentation / Support (10%) | Brand / Reliability (5%) | Total Score | Notes
VEVOR 3HP 120V VFD | 9 | 6 | 5 | 4 | 4 |  | Lowest cost ($70–95). Hobby-grade, limited docs.
110V 20A 3HP VFD | 8 | 7 | 6 | 5 | 5 |  | Best balance ($130–150). Good for 20A circuits.
Huanyang 3HP VFD | 7 | 7 | 6 | 5 | 5 |  | Common CNC choice ($120–200). Verify seller/specs.
ATO 3HP 120V VFD | 5 | 9 | 8 | 7 | 7 |  | Higher quality but too expensive ($450–500).

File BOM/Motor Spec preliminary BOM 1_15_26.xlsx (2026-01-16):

ID | Model / Type | HP | Voltage | RPM | Type | Price (Est.) | Key Features | ID | Model / Type | HP | Voltage | RPM | Type | Price (Est.) | Key Features | Web links
1 | WEG Single Phase | 3 | 115/230V | 1730 | 1-Ph Gen Purp | $460 - $495 | High torque, versatile voltage. | 1 | Marathon G0532 Gearmotor | 2 | 115V | 160 | Cap-Start Gear | $420 - $480 | Integrated gearbox; best value. | https://www.electricmotorwholesale.com/leeson-1ph-gearmotors/
2 | Worldwide Electric NT3-18-213T | 3 | 208-230V | 1800 | 3-Ph TEFC | $310 - $340 | Efficient, requires VFD for 1-Ph power. | 2 | WEG W21 2HP | 2 | 230/460V | 1750 | 3-Ph Industrial | $240 - $290 | Rigid frame; needs VFD for speed. | https://canadianforge.com/products/baldor-grinder
3 | VEVOR High Torque Motor | 5 | 230V | 3450 | 1-Ph Compressor | $210 - $260 | Most HP for the price; high RPM. | 3 | TECO L510 VFD (2HP) | N/A | 115V | N/A | Control | $210 - $240 | Converts 115V wall power to 3-Ph. | https://www.pumpdepot.us/product/weg-motor-w22-5hp-230v-1ph-60-hz-1730rpm-tefc-foot-mounted-model-00518es1c184t-w22/
4 | TECO L510 VFD (3HP) | N/A | 230V | N/A | Control | $240 - $280 | Adds speed control to 3-Ph motors. | 4 | KB Electronics KBWC-15K | N/A | 115V | N/A | Control | $45 - $70 | Simple triac speed control (Fan/Pump). | https://www.raptorsupplies.com/c/motors/p/farm-duty-motors
 |  |  |  |  |  |  |  |  |  |  |  |  |  |  |  | https://www.baldor.com/catalog/M3705T
Category | Item Description | Function | Qty | Est. Unit Price |  |  |  |  |  |  |  |  |  |  |  | https://www.electricmotorwholesale.com/leeson-dc-gearmotor-subfhp/
Prime Mover | [Motor Placeholder] | Main drive for shredder cutters | 1 | TBD |  |  |  |  |  |  |  |  |  |  |  | https://www.usabluebook.com/theme/weg-2-hp-motor
Control | [VFD Placeholder] | Motor speed and torque regulation | 1 | TBD
Protection | Main Disconnect Switch | Emergency power isolation (Lockable) | 1 | $120.00 |  |  |  |  |  |  |  |  |  |  |  | https://us.emotorsdirect.ca/item/kb-electronics-kbac-29-black-2
Protection | Circuit Breakers (Main & Branch) | Short-circuit and overload protection | 2 | $55.00 |  |  |  |  |  |  |  |  |  |  |  | https://www.wolfautomation.com/l510-201-h1-u-vfd-1hp-230v-single-phase
Protection | Current Monitoring Relay | Detects jams to trigger auto-reverse | 1 | $85.00
Safety | Emergency Stop Button | Safety shutdown (Twist-to-Reset) | 1 | $45.00 |  |  |  |  |  |  |  |  |  |  |  | https://www.google.com/search
Safety | Safety Interlock Switch | Prevents operation if hopper is open | 1 | $65.00 |  |  |  |  |  |  |  |  |  |  |  | https://www.google.com/search
Interface | Industrial HMI / Touchscreen | Operator controls and status display | 1 | $350.00 |  |  |  |  |  |  |  |  |  |  |  | https://www.google.com/search?q=https://us.emotorsdirect.ca/item/kb-electronics-kbac-24d-9520
Switching | Power Contactor | Main power switching for the VFD/Motor | 1 | $75.00 |  |  |  |  |  |  |  |  |  |  |  | https://www.google.com/search?q=https://www.ato.com/2hp-vfd-110v-120v-input
DC Power | 24VDC Power Supply (https://google.com/search?ibp=oshop&igu=1&pvo=38&opi=103135050&gl=us&hl=en&noiga=1) | Powers HMI, PLC, and control logic | 1 | $40.00
Enclosure | NEMA 12/4 Steel Enclosure | Dust-tight housing for all electronics | 1 | $220.00
Thermal | Enclosure Cooling Fan & Filter | Prevents VFD from overheating | 1 | $60.00
Wiring | 8 AWG MTW Power Wire | High-current wiring for motor/VFD | 50 ft | $1.75/ft
Wiring | 18 AWG Blue Control Wire | 24VDC Control circuit wiring | 100 ft | $0.25/ft
Hardware | DIN Rail & Wire Duct | Organizing components and cables | 1 set | $45.00
Hardware | Cable Glands & Entry Seals | Sealed entry for wires into enclosure | 6 | $8.00
Hardware | DIN Rail Terminal Blocks | Connection points for internal wiring | 25 | $3.00

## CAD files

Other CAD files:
CAD/Parts/Part1/Part1.ipt
CAD/Parts/Part10/Part10.ipt
CAD/Parts/Part2/Part2.ipt
CAD/Parts/Part3/Part3.ipt
CAD/Parts/Part4/Part4.ipt
CAD/Parts/Part5/Part5.ipt
CAD/Parts/Part6/Part6.ipt
CAD/Parts/Part7/Part7.ipt
CAD/Parts/Part8/Part8.ipt
CAD/Parts/Part9/Part9.ipt

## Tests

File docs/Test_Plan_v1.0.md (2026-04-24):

# Test Plan v1.0 — Universal Plastic Shredder V2.0 Electrical System

**Course:** ECE 412 Senior Project Development, Portland State University  
**Sponsor:** MME / Ichor Systems (Bridget Lannigan)  
**Team:** Bao Nguyen, Fearghus Tyler, Yaqoub Rabiah, Fox Kang  
**Date of Test:** ___________  
**Tester:** ___________

---

## Purpose

To verify the electrical control system of the Universal Plastic Shredder V2.0 against its requirements, using both top-down (full-system operational) and bottom-up (subsystem-by-subsystem) test methods.

---

## Equipment Needed

### System Equipment
- Shredder electrical enclosure (PLC, VFD, contactor, fuse blocks, PSU, wiring complete)
- EA9-T6CL-R C-More HMI touch panel (mounted, cabled)
- 3–5 HP motor + gearbox (ME interface, mechanically coupled)
- E-stop button, two-hand start buttons (Fwd, Deadman SW1/SW2), lid interlock switch
- Status indicator lights (Power / Running / Fault)
- AC power cord/supply (120 VAC or 208–240 VAC, as applicable)

### Test Equipment
- Digital multimeter (voltage, continuity, current clamp)
- Tachometer or optical RPM sensor (to verify shaft speed)
- Clamp-on ammeter (motor current)
- Laptop with DirectSOFT5 (PLC programming software) and USB-to-serial adapter
- C-More programming cable + EA-MG-PGM-CBL software cable (for HMI)
- Sample plastic pieces: PVC, PP, or LDPE sheet, 0.25–0.5" thick, 4–12" wide

### Other Equipment
- Personal protective equipment: safety glasses, hearing protection
- Fire extinguisher (Class C, electrical)
- Second person present for all powered tests (safety requirement for industrial equipment)

---

## Pre-Test Setup

1. Confirm the area around the shredder is clear of loose material.
2. Confirm the lid interlock switch is functional: manually actuate it and verify the NC contact opens/closes with a multimeter before powering on.
3. Set the AC power supply to match the system's rated input voltage. Verify with a multimeter before connecting.
4. Confirm all wiring terminations are secure (no loose lugs, no exposed conductors).
5. Confirm fuses are seated: 25A (PSU branch), 1A (PLC branch), 1.5A (pushbutton commons), 1/2A slow-blow (contactor coil fuse DF103V).
6. Connect DirectSOFT5 laptop to the H2-DM1E CPU via Ethernet or serial — confirm communication before starting tests.
7. Confirm the VFD (HY02D211B-T) is powered off and the contactor (SD-N35) is open before initial power-on.
8. Place test plastic material near the input chute but do not feed until instructed.

---

## Part 1: Top-Down Test

*Tests M1, M2, M4, M6, M7, M9, S1, S3*

### Top-Down Test Steps

**Phase 1 — Power On**

1. Switch on main AC disconnect / power switch.
   - **Power indicator light** (status light) should illuminate. ☐  *Tests: S1 (power indicator)*
   - Measure 24VDC at PSU output terminals. Should be 24 ± 2 VDC. Reading: _______ V  
   - PLC CPU (H2-DM1E) should boot — RUN LED on CPU should go green within ~5 seconds. ☐

2. Observe HMI display (EA9-T6CL-R).
   - Display should power on and show **"IDLE / READY"** state screen. ☐  *Tests: M9 (HMI powers on)*
   - Confirm system state shown on HMI reads: **Idle** ☐  *Tests: M9 (state display)*

**Phase 2 — Safety Pre-check (lid open, no start)**

3. Confirm lid interlock is triggered (lid open or switch manually held open).
   - Attempt to press Forward button.
   - Motor must NOT start. ☐  *Tests: M6 (lid interlock prevents run)*
   - HMI should display fault or interlock message. ☐

4. Close lid (or release interlock switch). HMI should return to Ready/Idle state. ☐

**Phase 3 — Normal Start Sequence**

5. With lid closed, press and hold both Deadman SW1 and SW2 simultaneously, then press Forward.
   - Contactor (SD-N35) should close (audible click). ☐
   - Motor should begin spinning. ☐
   - **Running indicator light** should illuminate. ☐  *Tests: S1 (running indicator)*
   - HMI should display **"Running"** state and current motor speed (RPM or Hz). ☐  *Tests: M9 (running state display)*

6. Allow motor to reach steady-state speed (~5 seconds). Measure output shaft RPM with tachometer.
   - Reading: _______ RPM. Should be 70–90 RPM. ☐  *Tests: M7 (speed in range)*
   - If speed is outside range, note VFD frequency command and adjust as needed.

**Phase 4 — Shred Test**

7. With motor running at target speed, hand-feed one plastic test piece (0.25–0.5" thick, 4–12" wide) into the input chute.
   - Shredder should accept and process the piece without stalling or faulting. ☐
   - Collect output — pieces should be approximately 1" in size. ☐  *Tests: M1 (shreds to ~1")*
   - Motor should return to target RPM after piece clears. ☐

**Phase 5 — Normal Stop**

8. Release one or both Deadman buttons (or press Stop if available on HMI).
   - Motor should stop (contactor opens). ☐
   - Running light should extinguish. ☐
   - HMI should return to **"Idle"** state. ☐

**Phase 6 — Emergency Stop**

9. Restart motor per Step 5. Confirm motor is running.
10. Press E-stop button.
    - Motor must stop immediately (contactor drops out). ☐  *Tests: M4 (E-stop shuts down)*
    - Running light should extinguish. ☐
    - HMI should display **"Fault / E-stop"** state. ☐  *Tests: M9 (fault state display)*
    - **Fault indicator light** should illuminate. ☐  *Tests: S1 (fault indicator)*

11. Twist/release E-stop button to reset.
    - Confirm system returns to Idle (motor does not auto-restart). ☐  *Tests: M4 (no auto-restart after E-stop)*

**Phase 7 — Power Off**

12. Switch off main AC disconnect.
    - All lights should extinguish. HMI should power off. Motor (if running) should stop. ☐

### Top-Down Test Conclusions

| Requirement | Result | Notes |
|---|---|---|
| M1 — Shreds to ~1" | ☐ Pass ☐ Fail | |
| M2 — VFD used and controllable | ☐ Pass ☐ Fail | |
| M4 — E-stop shuts down safely | ☐ Pass ☐ Fail | |
| M6 — Lid interlock prevents run | ☐ Pass ☐ Fail | |
| M7 — 70–90 RPM shaft speed | ☐ Pass ☐ Fail | Measured: _____ RPM |
| M9 — HMI shows state and control | ☐ Pass ☐ Fail | |
| S1 — Status/fault lights work | ☐ Pass ☐ Fail | |
| S3 — Controls clearly labeled | ☐ Pass ☐ Fail | |

---

## Part 2: Bottom-Up Test

---

### Test Case BU-01: AC Power Input and Fuse Block

| | |
|---|---|
| **Test ID** | BU-01 |
| **Test Case Name** | AC Power Input and Fuse Distribution |
| **Description** | Verify AC power reaches the fuse block and distributes correctly to the PSU and PLC branches. |
| **Type** | Black box |
| **Tester** | |
| **Date** | |
| **HW/SW Version** | 1.0 |
| **Setup** | Main disconnect OFF. Multimeter set to AC voltage. |

| # | Input | Expected Output | Pass | Fail | N/A | Comments |
|---|---|---|---|---|---|---|
| 1 | Main disconnect ON | AC line voltage present at EURO S10H-5H fuse block input (measure L and N terminals) | ☐ | ☐ | ☐ | Reading: _____ VAC |
| 2 | Main disconnect ON | 25A fuse branch: AC present at PSU input terminals | ☐ | ☐ | ☐ | |
| 3 | Main disconnect ON | 1A fuse branch: AC present at PLC L terminal | ☐ | ☐ | ☐ | |
| 4 | Pull 25A fuse (disconnect first) | AC removed from PSU branch; PLC branch unaffected | ☐ | ☐ | ☐ | |
| 5 | Reinstate 25A fuse | Normal distribution restored | ☐ | ☐ | ☐ | |

**Overall BU-01 Result:** ☐ Pass ☐ Fail

---

### Test Case BU-02: 24VDC Power Supply

| | |
|---|---|
| **Test ID** | BU-02 |
| **Test Case Name** | 24VDC PSU Output (Mean Well NDR-480-24) |
| **Description** | Verify the PSU outputs correct 24VDC to PLC I/O, contactor coil, and pushbutton commons. |
| **Type** | Black box |
| **Tester** | |
| **Date** | |
| **HW/SW Version** | 1.0 |
| **Setup** | AC power ON. Multimeter set to DC voltage. |

| # | Input | Expected Output | Pass | Fail | N/A | Comments |
|---|---|---|---|---|---|---|
| 1 | AC applied to PSU | +V terminal: 24 ± 2 VDC at PSU output | ☐ | ☐ | ☐ | Reading: _____ VDC |
| 2 | AC applied to PSU | –V terminal: 0V (return) | ☐ | ☐ | ☐ | |
| 3 | AC applied | 1.5A fused pushbutton commons: 24VDC at each common (Fwd, Rev, DM1, DM2) | ☐ | ☐ | ☐ | |
| 4 | AC applied | Contactor coil A2 terminal: 0VDC (contactor open at rest) | ☐ | ☐ | ☐ | |

**Overall BU-02 Result:** ☐ Pass ☐ Fail

---

### Test Case BU-03: PLC Boot and Communication

| | |
|---|---|
| **Test ID** | BU-03 |
| **Test Case Name** | PLC Rack Initialization (DirectLOGIC 205) |
| **Description** | Verify the PLC CPU boots, all modules are recognized, and DirectSOFT5 can read I/O status. |
| **Type** | White box |
| **Tester** | |
| **Date** | |
| **HW/SW Version** | 1.0 |
| **Setup** | AC power ON. DirectSOFT5 open on laptop and connected to H2-DM1E via Ethernet. |

| # | Input | Expected Output | Pass | Fail | N/A | Comments |
|---|---|---|---|---|---|---|
| 1 | Power on PLC | CPU RUN LED: solid green within 10 seconds | ☐ | ☐ | ☐ | |
| 2 | DirectSOFT5 connect | PLC goes online; no I/O errors reported | ☐ | ☐ | ☐ | |
| 3 | DirectSOFT5 data view | All discrete inputs X0–X7 readable (0 or 1) | ☐ | ☐ | ☐ | |
| 4 | DirectSOFT5 data view | All discrete outputs Y0–Y7 readable (0 at startup) | ☐ | ☐ | ☐ | |
| 5 | DirectSOFT5 data view | Analog input F2-06AD-1 registers readable | ☐ | ☐ | ☐ | |
| 6 | DirectSOFT5 data view | RTD input F2-04RTD registers readable; ambient temp reasonable (15–30 °C) | ☐ | ☐ | ☐ | Reading: _____ °C |
| 7 | Ladder logic running | No ladder logic errors or fault codes in CPU status | ☐ | ☐ | ☐ | |

**Overall BU-03 Result:** ☐ Pass ☐ Fail

---

### Test Case BU-04: Emergency Stop Circuit

| | |
|---|---|
| **Test ID** | BU-04 |
| **Test Case Name** | E-Stop Hardware Safety Circuit |
| **Description** | Verify the E-stop button breaks the safety circuit and drops all motor-related outputs. Tests M4. |
| **Type** | Black box |
| **Tester** | |
| **Date** | |
| **HW/SW Version** | 1.0 |
| **Setup** | AC power ON, PLC running ladder logic. Motor is NOT running. Multimeter on safety circuit nodes. |

| # | Input | Expected Output | Pass | Fail | N/A | Comments |
|---|---|---|---|---|---|---|
| 1 | E-stop released (normal) | Safety circuit continuity: confirmed (multimeter, or circuit logic per deadman_logic2.pdf) | ☐ | ☐ | ☐ | |
| 2 | Press E-stop | Safety circuit opens immediately | ☐ | ☐ | ☐ | |
| 3 | Press E-stop while motor running (from BU-07 run) | Contactor (SD-N35) drops out within 1 second | ☐ | ☐ | ☐ | |
| 4 | Press E-stop | Y0 (contactor coil output) = 0 in DirectSOFT5 | ☐ | ☐ | ☐ | |
| 5 | Release E-stop (twist/pull) | System does NOT auto-restart motor | ☐ | ☐ | ☐ | |
| 6 | Release E-stop, then re-initiate two-hand start | Motor can restart normally after E-stop reset | ☐ | ☐ | ☐ | |

**Overall BU-04 Result:** ☐ Pass ☐ Fail

---

### Test Case BU-05: Two-Hand Start / Deadman Circuit

| | |
|---|---|
| **Test ID** | BU-05 |
| **Test Case Name** | Two-Hand Start (Deadman) Safety Logic |
| **Description** | Verify the motor only runs when both deadman buttons are held simultaneously with Forward. Tests M6. |
| **Type** | Black box |
| **Tester** | |
| **Date** | |
| **HW/SW Version** | 1.0 |
| **Setup** | AC power ON, PLC running, E-stop released, lid closed. Per deadman_logic2.pdf. |

| # | Input | Expected Output | Pass | Fail | N/A | Comments |
|---|---|---|---|---|---|---|
| 1 | Press Forward only (no deadman) | Motor does NOT start | ☐ | ☐ | ☐ | |
| 2 | Press SW1 only (no Forward) | Motor does NOT start | ☐ | ☐ | ☐ | |
| 3 | Press SW2 only (no Forward) | Motor does NOT start | ☐ | ☐ | ☐ | |
| 4 | Press SW1 + SW2 (no Forward) | Motor does NOT start | ☐ | ☐ | ☐ | |
| 5 | Press Forward + SW1 only | Motor does NOT start | ☐ | ☐ | ☐ | |
| 6 | Press Forward + SW2 only | Motor does NOT start | ☐ | ☐ | ☐ | |
| 7 | Press Forward + SW1 + SW2 simultaneously | Contactor closes, motor starts | ☐ | ☐ | ☐ | |
| 8 | While running: release SW1 | Motor stops immediately | ☐ | ☐ | ☐ | |
| 9 | While running: release SW2 | Motor stops immediately | ☐ | ☐ | ☐ | |

**Overall BU-05 Result:** ☐ Pass ☐ Fail

---

### Test Case BU-06: Lid Interlock

| | |
|---|---|
| **Test ID** | BU-06 |
| **Test Case Name** | Lid Interlock Safety Input |
| **Description** | Verify the lid interlock switch (discrete input to PLC) prevents motor from running when triggered. Tests M6. |
| **Type** | Black box |
| **Tester** | |
| **Date** | |
| **HW/SW Version** | 1.0 |
| **Setup** | AC power ON, PLC running, E-stop released. Interlock switch accessible. |

| # | Input | Expected Output | Pass | Fail | N/A | Comments |
|---|---|---|---|---|---|---|
| 1 | Lid closed (interlock normal) | PLC discrete input for interlock reads correct state in DirectSOFT5 (note address: ___) | ☐ | ☐ | ☐ | |
| 2 | Open lid (trigger interlock) | Interlock DI changes state in PLC | ☐ | ☐ | ☐ | |
| 3 | Lid open, attempt two-hand start | Motor does NOT start | ☐ | ☐ | ☐ | |
| 4 | Motor running, then open lid | Motor stops within 1 second | ☐ | ☐ | ☐ | |
| 5 | Close lid, reset, re-initiate start | Motor starts normally | ☐ | ☐ | ☐ | |

**Overall BU-06 Result:** ☐ Pass ☐ Fail

---

### Test Case BU-07: VFD Control and Motor Speed

| | |
|---|---|
| **Test ID** | BU-07 |
| **Test Case Name** | VFD Speed Command and Motor RPM (HY02D211B-T) |
| **Description** | Verify PLC analog output CH1 commands correct VFD speed and output shaft reaches 70–90 RPM. Tests M2, M7, M8. |
| **Type** | White box |
| **Tester** | |
| **Date** | |
| **HW/SW Version** | 1.0 |
| **Setup** | AC power ON, PLC running, safety circuits clear, motor mechanically coupled. Tachometer and multimeter ready. |

| # | Input | Expected Output | Pass | Fail | N/A | Comments |
|---|---|---|---|---|---|---|
| 1 | Motor stopped | Measure AO CH1 voltage at VFD terminal AL: ~0V | ☐ | ☐ | ☐ | Reading: _____ V |
| 2 | Initiate two-hand start | Contactor (SD-N35) closes (audible click, LED if present) | ☐ | ☐ | ☐ | |
| 3 | Motor running | AO CH1 voltage at VFD AL terminal: 0–10VDC, nonzero | ☐ | ☐ | ☐ | Reading: _____ V |
| 4 | Motor running at steady state | Tachometer at output shaft: 70–90 RPM | ☐ | ☐ | ☐ | Reading: _____ RPM |
| 5 | Motor running | Clamp ammeter on motor leads: within motor nameplate FLA (Full Load Amps) | ☐ | ☐ | ☐ | Reading: _____ A |
| 6 | Motor running | VFD keypad display: no fault codes (Er.xxx) | ☐ | ☐ | ☐ | |
| 7 | Normal stop (release deadman) | VFD ramps down; shaft stops within _____ seconds | ☐ | ☐ | ☐ | |

**Overall BU-07 Result:** ☐ Pass ☐ Fail

---

### Test Case BU-08: Overcurrent and Overload Protection

| | |
|---|---|
| **Test ID** | BU-08 |
| **Test Case Name** | Overcurrent / Overload Protection (M5) |
| **Description** | Verify the Phoenix Contact motor overload (TMC 83C 15A) and thermal overload (RTD32-180) respond to fault conditions. Tests M5. |
| **Type** | Black box |
| **Tester** | |
| **Date** | |
| **HW/SW Version** | 1.0 |
| **Setup** | AC power ON. Do NOT intentionally overload the motor to destruction; use the trip test button if the overload relay has one, or verify NC contact behavior with multimeter. |

| # | Input | Expected Output | Pass | Fail | N/A | Comments |
|---|---|---|---|---|---|---|
| 1 | Motor stopped | Phoenix Contact TMC 83C NC contact: closed (continuity) | ☐ | ☐ | ☐ | |
| 2 | Press trip/test button on TMC 83C (if available) | NC contact opens; motor contactor cannot close | ☐ | ☐ | ☐ | |
| 3 | Reset TMC 83C | NC contact closes; system restores | ☐ | ☐ | ☐ | |
| 4 | Motor running at rated load | Clamp ammeter: motor current ≤ rated FLA | ☐ | ☐ | ☐ | Reading: _____ A |
| 5 | RTD32-180 thermal overload (OUT3 path) | Verify NC contact (95→96) is in series with F2 contactor coil per wiring diagram | ☐ | ☐ | ☐ | |
| 6 | Simulate thermal trip (if test mode available) | OUT3 drives thermal overload trip; motor stops | ☐ | ☐ | ☐ | |

**Overall BU-08 Result:** ☐ Pass ☐ Fail

---

### Test Case BU-09: HMI Display and State Feedback

| | |
|---|---|
| **Test ID** | BU-09 |
| **Test Case Name** | HMI Operator Interface (EA9-T6CL-R C-More) |
| **Description** | Verify the HMI displays correct system state, speed, and faults, and that operator inputs on HMI are reflected in the system. Tests M9. |
| **Type** | Black box |
| **Tester** | |
| **Date** | |
| **HW/SW Version** | 1.0 |
| **Setup** | AC power ON, PLC running, HMI powered (via Rhino PSB12-030-P). HMI-to-PLC serial link active. |

| # | Input | Expected Output | Pass | Fail | N/A | Comments |
|---|---|---|---|---|---|---|
| 1 | Power on | HMI shows system state: Idle or Ready | ☐ | ☐ | ☐ | |
| 2 | Motor running (via two-hand start) | HMI shows: Running state | ☐ | ☐ | ☐ | |
| 3 | Motor running | HMI displays current motor speed or VFD Hz | ☐ | ☐ | ☐ | |
| 4 | Press E-stop | HMI shows: Fault / E-stop state | ☐ | ☐ | ☐ | |
| 5 | Trigger lid interlock | HMI shows interlock fault or warning | ☐ | ☐ | ☐ | |
| 6 | Reset E-stop | HMI returns to Idle (no auto-restart) | ☐ | ☐ | ☐ | |
| 7 | HMI Stop (if implemented) | Motor stops when Stop pressed on HMI | ☐ | ☐ | ☐ | N/A if not implemented |

**Overall BU-09 Result:** ☐ Pass ☐ Fail

---

### Test Case BU-10: Status Indicator Lights

| | |
|---|---|
| **Test ID** | BU-10 |
| **Test Case Name** | Status Indicator Lights (Power / Running / Fault) |
| **Description** | Verify the three status lights illuminate in the correct system states. Tests S1. |
| **Type** | Black box |
| **Tester** | |
| **Date** | |
| **HW/SW Version** | 1.0 |
| **Setup** | AC power ON, PLC running. |

| # | System State | Power Light | Running Light | Fault Light | Pass | Fail | Comments |
|---|---|---|---|---|---|---|---|
| 1 | Power ON, Idle | ON | OFF | OFF | ☐ | ☐ | |
| 2 | Motor Running | ON | ON | OFF | ☐ | ☐ | |
| 3 | E-stop active | ON | OFF | ON | ☐ | ☐ | |
| 4 | Lid interlock fault | ON | OFF | ON | ☐ | ☐ | |
| 5 | Power OFF | OFF | OFF | OFF | ☐ | ☐ | |

**Overall BU-10 Result:** ☐ Pass ☐ Fail

---

## Requirements Coverage Summary

| Req ID | Requirement | BU Test(s) | Top-Down | Result |
|---|---|---|---|---|
| M1 | Shreds plastic to ~1" | — | Phase 4 | ☐ Pass ☐ Fail |
| M2 | Controllable VFD | BU-07 | Phase 3 | ☐ Pass ☐ Fail |
| M3 | NFPA-70 (NEC) design | BU-01, BU-02 (inspect wiring) | — | ☐ Pass ☐ Fail |
| M4 | E-stop safe shutdown | BU-04 | Phase 6 | ☐ Pass ☐ Fail |
| M5 | Overcurrent/overload protection | BU-08 | — | ☐ Pass ☐ Fail |
| M6 | Safety interlock (lid + two-hand) | BU-05, BU-06 | Phase 2 | ☐ Pass ☐ Fail |
| M7 | 70–90 RPM shaft speed | BU-07 | Phase 3 | ☐ Pass ☐ Fail |
| M8 | VFD supports 3–5 HP motor | BU-07 | — | ☐ Pass ☐ Fail |
| M9 | HMI for control and status | BU-09 | Phase 1, 3, 6 | ☐ Pass ☐ Fail |
| M10 | Total cost ≤ $3,000 | BOM review | — | ☐ Pass ☐ Fail |
| S1 | Status/fault indicator lights | BU-10 | Phase 1, 3, 6 | ☐ Pass ☐ Fail |
| S2 | NEMA enclosure practices | Visual inspection | — | ☐ Pass ☐ Fail |
| S3 | Controls clearly labeled | Visual inspection | — | ☐ Pass ☐ Fail |

---

## Post-Test Teardown

1. Press E-stop (if not already active).
2. Switch off main AC disconnect.
3. Wait 60 seconds for VFD DC bus capacitors to discharge before opening enclosure.
4. Disconnect laptop from PLC.
5. Remove any test plastic material from input chute and output collection area.
6. Cover or secure enclosure.

---

## Test Notes / Discussion

*(Record any anomalies, deviations from expected results, or items requiring follow-up here.)*

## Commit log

2026-01-13 Add files via upload
    Rudimentary BOM for our project.
    [BOM.xlsx]
2026-01-16 Add files via upload
    Possible Motor options, 2-5 hp both industrial and typical voltages.
    [Motor Spec.xlsx]
2026-01-30 Add files via upload
    Add some potential components we may be used in excel
    [BOM_1_30_beta.xlsx]
2026-02-06 Add files via upload
    Ladder Logic pertaining the deadman switches. Really basic, and turns the motor on and off.
2026-02-13 Add files via upload
    Circuit ladder logic. Little more advance than the last one
2026-04-14 updated ladder logic
    includes rpm scale, deadman switches rework, forwards and backwards buttons and functionality
2026-04-20 Reorganize repo into structured folders
    - docs/: team contract, project proposal, HMI options matrix
    - BOM/: all bill of materials and component spec spreadsheets
    - CAD/: CAPSTONE_CAD.zip and Parts/ (Part1–Part10 Inventor .ipt files)
    - electrical/: circuit and deadman logic diagrams
    - PLC/: shredder ladder logic
    - HMI/: HMI project file
    [BOM_02_20_26.xlsx, BOM_1_29.xlsx, BOM_1_30_beta.xlsx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]
2026-04-20 Add CSV versions of point list for GitHub viewing
    [Point List - Direct Logic 205 D2-09B-1.csv, Point List - DirectLOGIC CPU (H2-DM1E).csv, Point List - HMI (EA9-T6CL-R).csv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]
2026-04-20 Combine point list sheets into single CSV
    [Point List - Direct Logic 205 D2-09B-1.csv, Point List - DirectLOGIC CPU (H2-DM1E).csv, Point List - HMI (EA9-T6CL-R).csv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]
2026-04-20 Replace CSV with PDF version of point list
    [Point List.csv]
2026-04-24 rework circuit logic
